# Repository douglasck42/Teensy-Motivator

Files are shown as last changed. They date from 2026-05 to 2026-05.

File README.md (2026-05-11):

# Teensy-Motivator
Teensy 4.1 Based Droid Control. This code coveres the primary Teensy 4.1 system which it's primary job is converting inputs to outputs, trigging programmatic automation of events, triggering MP3s and LED sequences, and even override normal input/output maps for the purposes of automation.

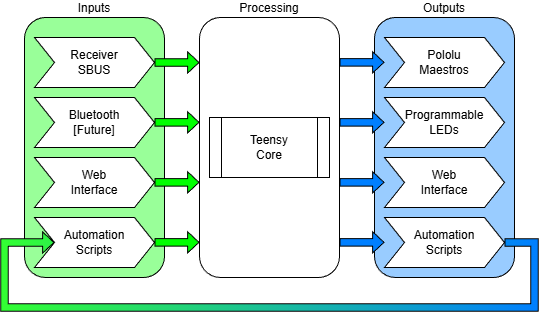
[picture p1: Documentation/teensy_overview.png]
Teensy 4.1 Overview


## System Architecture
* Core System - This `Teensy Motivator` Repository
    * Teensy 4.1
    * DFPlayer Mini
    * Pololu D36V50F5 5v Voltage Regulator (accepting 5.5-50v DC input)
    * An available PCB Board simplifying the mounting of all of this (Hardware v1.0)
* Control System - Optional - `Teensy Scomp Link` Repository
    * Adafruit Sparkle Mini ESP32 Arduino
    * Attached via Serial Port to the Teensy 4.1
    * Provides 2 banks of WS2812b or 5050 LEDs
    * Provides Wireless Control - both a Web Interface and remote triggers via ESP-NOW
* Remote System - Optional - `Teensy Scomp Relay` Repository
    * Adafruit Sparkle Mini ESP32 Arduino
    * Provides 2 banks of WS2812b or 5050 LEDs
    * Listens for ESP-NOW Triggers to run LED animations
* KyberPad
    * From the Kyber team - Provides LUA scripts for up to 3 screens of 15 buttons each
    * Enables the triggering of MP3s, Automation, Etc
    * Seperate Purchase required

## Inputs:
    - Single Input: SBUS-16 or SBUS-24
    - Web Interface `Teensy Scomp Link`
    - KyberPad R/C Triggers
    - Serial Console for debugging and test bench work

## Outputs:
    - LEDs: Triggered via Serial communications Adafruit Sparkle
    - Serial2: DFPlayer music trigger
    - Serial3: Pololu Maestro or Similar (MARCduino, etc)
    - Serial4: Pololu Maestro or Similar (MARCduino, etc)
    - Serial5: Teensy Scomp Link (Adafruit Sparkle Motion)
    - Serial6: Pololu Maestro or Similar (MARCduino, etc)
    - Serial7: Pololu Maestro or Similar (MARCduino, etc)
    - Serial8: SBUS (FrSky Receiver)
    - Can Bus 1: Robotic Actuators, etc
    - Can Bus 3: Robotic Actuators, etc
    - Web Interface via Wi-Fi (status messages, etc)
    - Two GPIO Pins (11,12 and 40, 41) - Future Possibilities
    - I2C - Future Possibilities

## LED Animations
    - (TBD...)

## Maestro Serial Animations
    # 1-Axis Random Idle - Randomly Move a servo
    # 2-Axis Random Idle - Randomly Move a servo
    # 2-Axis Random Spinner - Randomly trigger DC Motor spins (B2EMO Tool Spinners)
    # 2-Axis Fixed Spinner - trigger DC Motor spins on a set sequence (B2EMO Tool Spinners)
    # 3-Axis Random Head Idle - Given 3 axis, randomly move a head unit around (BB-8 or B2EMO Simple Head)
    # 4-Axis Random Head Idle - Given 4 axis, randomly move a head unit around (B2EMO DF-Pro Head)
    
# FrSky SBUS Tuning
The FrSky SBUS does not have great documentation.

## SBUS-16 or SBUS-24
First things first, right now it's a compiled setting. Pick on and that's that.

## SBUS Min/Max
If all of you outputs DO NOT exceed 100% then you can ignore this section. If you want more granular control below that, you may need to tune the min/max

If you outputs are **RESTRICTED below 100%**, you probably STILL want to **IGNORE THIS section**

If this isn't mapped properly, you won't get to min/max ratios proper. Either coming up short or blowing past a software limiter. If you're using Pololu Maestros those values, if changed, must match as well!

For SBUS, at **100%** from the FrSky transmitter, Minimum SBUS is `172` and maximum is `1810` - You change the `sbus_standard_min` and `sbus_standard_max` values if desired for default all-channel behavior.

For SBUS, at **125%** from the FrSky transmitter, Minimum SBUS is `0` and maximum is `2047` but in practice, I've only seen and configured the system for `8` and `1976`. You change the `sbus_abs_min` and `sbus_abs_max` values if desired for default all-channel behavior. 

Going above **125%** isn't supported, is discouraged by the FrSky transmitter GUI on the X20-RS, and I don't know what will happen.

Per-channel default is to use the system-wide standard values if the **per-channel default setting sbus_abs_minmax = false**. Setting **sbus_abs_minmax = true** uses the absolute full range values. Directly configuring channel[x].min and channel[x].max values uses THOSE no matter the boolean value.

## Reciever Output Warning
**On my lab bench, my TD SR6 cannot and will not transmit the absolute values (expanded range). The TD R6 and TD R10 CAN**. Unfortunatly you will have to expirement yourself to know for sure. 

*Both receivers on the v3.0.3 firmware which isn't even available for download for the TD R6*

## Pololu Maestros
As with the SBUS min/max values, if this isn't mapped properly, you won't get to min/max ratios proper. With the Maestro min/max you can't exceed that so you're safe, but if you want the physical min/max to match, these values MUST match.

The default maestro values are `992µs` min and `2000µs` max as defined by settings.maestro_standard_min and settings.maestro_standard_max

The absolute min/max maestro values are `496µs` and `2496µs` as defined by settings.maestro_abs_min and settings.maestro_abs_min.

As with SBUS, the per-channel setting of maestro_100_pct 

## License

Firmware:
This project’s firmware is licensed under the GNU General Public License v3.0 (GPL-3.0).

Third-party components:
This project includes third-party libraries, including SBUS from Bolder Flight Systems, licensed under the GNU Lesser General Public License v3.0 (LGPL-3.0). Any modifications to those libraries are provided in accordance with their licenses.

Use at your own risk. No warranty. Verify designs before manufacturing.

Authors Note:
I'm inspired by the openness of the "droid building" community - the sharing and freely publishing complex designs and the work effort to arrive at those. I don't expect this project to be as "off-the-shelf" as other niche products with closed ecosystems (they are needed), but I wanted something more open, free, and extensible. This is that effort. I started droid building with B2EMO, so I will limit my thanks to the names of individuals who have been attached to that effort: Michael Baddeley, David Ferreria, Tim Hebel for the 3d designs and plans, and Jason Charlton's Youtube build videos.

© 2026 Douglas Kempthorne (douglas@kempthorne.com)

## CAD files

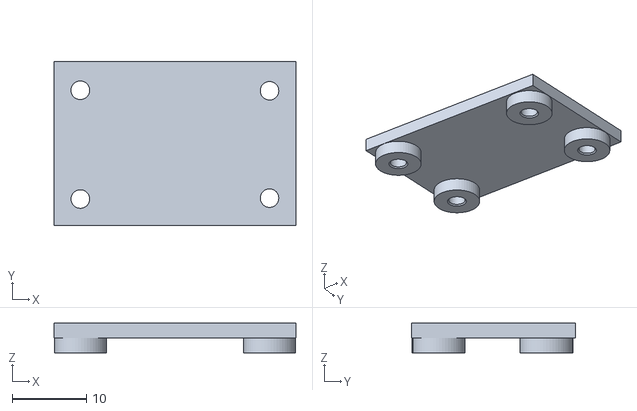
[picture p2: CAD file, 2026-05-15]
Documentation/Sparkle Mini PCB Surface Mount.stl
32.5 x 22.0 x 4.00

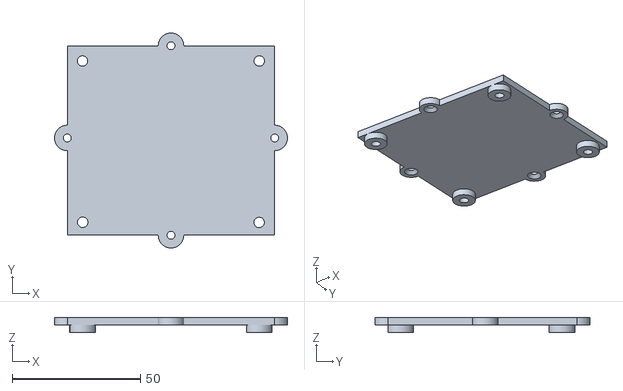
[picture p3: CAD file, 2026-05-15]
Documentation/Teensy Motivator v1.1 Surface Mount with Standoffs.stl
91.0 x 84.0 x 6.00

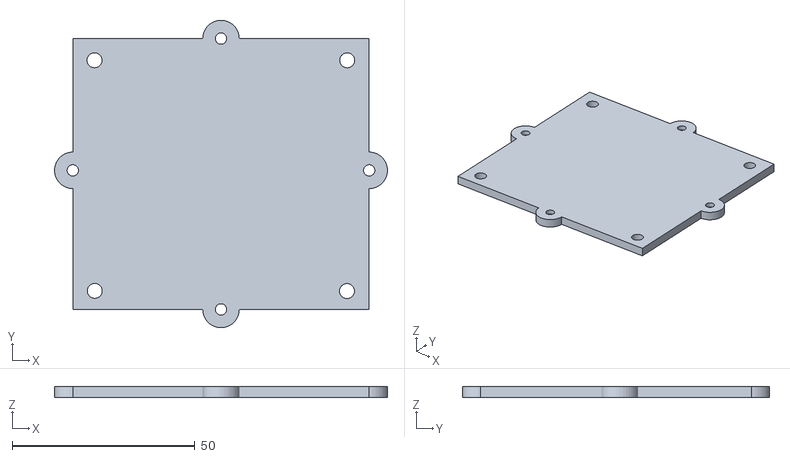
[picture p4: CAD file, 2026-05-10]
Documentation/Teensy Motivator v1.1 Surface Mount.stl
91.0 x 84.0 x 3.00

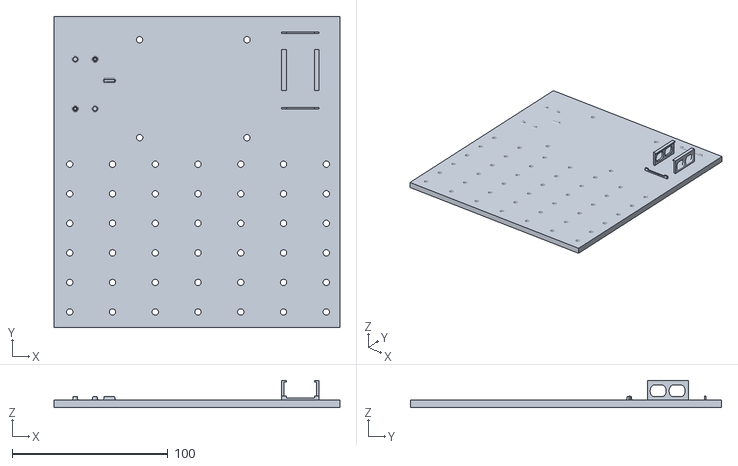
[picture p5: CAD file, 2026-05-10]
Documentation/Teensy Motivator v1.1 Work Surface.stl
183.7 x 200.0 x 17.5

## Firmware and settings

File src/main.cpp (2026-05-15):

// Copyright (c) 2026 Douglas Kempthorne (douglas@kempthorne.com)
// SPDX-License-Identifier: GPL-3.0-or-later

#define BUILD_VERSION "0.2.0"
#include <Arduino.h>
//#include <LittleFS.h>
#include "sbus/sbus_config.h"
#include "settings.h"
#include "dfplayer/dfp.h"
#include "kyberpad/kyberpad.h"
#include "maestro/maestro.h"
#include "json/JsonStorage.h"
#include "scomp/scomp_serial.h"

// Watching flags
#ifndef WATCHDOG_ENABLED
#define WATCHDOG_ENABLED 1
#endif
#ifndef WATCHDOG_TIMEOUT_SECONDS
#define WATCHDOG_TIMEOUT_SECONDS 10
#endif
#if WATCHDOG_ENABLED
#include <esp_task_wdt.h>
#endif

// Other timer values
#ifndef HEARTBEAT_INTERVAL_MS
#define HEARTBEAT_INTERVAL_MS 5000
#endif
#ifndef PRINT_ALL_INTERVAL_MS
#define PRINT_ALL_INTERVAL_MS 30000
#endif

#ifndef WAIT_FOR_SERIAL
#define WAIT_FOR_SERIAL 0
#endif

#ifndef DEBUG_SCOMP_RX
#define DEBUG_SCOMP_RX 0
#endif
#ifndef SCOMP_BAUD_RATE
#define SCOMP_BAUD_RATE 115200
#endif
static unsigned long millis_lastHeartbeat = 0;
static unsigned long g_last_scomp_ms = 0;


// Hand off the serial port here - Serial1 = pins 0/1 on Teensy 4.1
SbusDriverType sbusHandler(&SBUS_SERIAL);
Maestro maestro;
ScompSerial scomp;

// Define all functons:
void inputOutputMapping(uint8_t channel, unsigned long now);
void ioVolume(uint8_t channel);

char* formatUptime(unsigned long ms) {
    static char buf[32];
    unsigned long seconds = ms / 1000;
    unsigned long minutes = seconds / 60;
    unsigned long hours   = minutes / 60;
    unsigned long days    = hours   / 24;

    seconds %= 60;
    minutes %= 60;
    hours   %= 24;

    if (days > 0)
        sprintf(buf, "%lud %02luh %02lum %02lus", days, hours, minutes, seconds);
    else if (hours > 0)
        sprintf(buf, "%02luh %02lum %02lus", hours, minutes, seconds);
    else if (minutes > 0)
        sprintf(buf, "%02lum %02lus", minutes, seconds);
    else
        sprintf(buf, "%02lus", seconds);

    return buf;
}

// ========================= SCOMP =========================
void onScompMessage(uint8_t msg_type, const uint8_t *payload, uint16_t len, void *) {
    g_last_scomp_ms = millis();
    switch (msg_type) {
        case SCOMP_MSG_HEARTBEAT: {
            static unsigned long millis_lastEspHeartbeat = 0;
            unsigned long now_hb = g_last_scomp_ms;
            unsigned long gap = millis_lastEspHeartbeat ? (now_hb - millis_lastEspHeartbeat) : 0;
            millis_lastEspHeartbeat = now_hb;
            if (len >= sizeof(ScompHeartbeat)) {
                const auto *hb = reinterpret_cast<const ScompHeartbeat *>(payload);
                Serial.printf("Heartbeat: Teensy UP %s", formatUptime(now_hb));
                Serial.printf(" | Scomp UP %s", formatUptime(hb->uptime_ms));
                Serial.printf(" | v%u flags=0x%02X gap=%lums\n", hb->version, hb->flags, gap);
            } else {
                Serial.printf("Heartbeat: Teensy UP %s | Scomp FAULT | short payload %u bytes\n", formatUptime(now_hb), len);
            }
            break;
        }
        case SCOMP_MSG_REQUEST_STATE: {
            if (settings.system.debug) Serial.println("SCOMP: ESP32 requested state dump");
            // full state will be sent on the next scompSendState() tick
            break;
        }
        case SCOMP_MSG_SET_VOLUME: {
            if (len < sizeof(ScompSetVolume)) break;
            const auto *msg = reinterpret_cast<const ScompSetVolume *>(payload);
            uint8_t vol = constrain(msg->volume, settings.audio.min, settings.audio.max);
            dfpVolume(vol);
            settings.audio.volume = vol;
            if (settings.system.debug) Serial.printf("SCOMP: Set volume → %u\n", vol);
            break;
        }
        case SCOMP_MSG_TRIGGER_AUDIO: {
            if (len < sizeof(ScompTriggerAudio)) break;
            const auto *msg = reinterpret_cast<const ScompTriggerAudio *>(payload);
            dfpPlay(msg->file_number);
            if (settings.system.debug) Serial.printf("SCOMP: Trigger audio → file %u\n", msg->file_number);
            break;
        }
        case SCOMP_MSG_SET_SETTING: {
            if (len < sizeof(ScompSetSetting)) break;
            const auto *msg = reinterpret_cast<const ScompSetSetting *>(payload);
            if (settings.system.debug) Serial.printf("SCOMP: Set setting key=0x%02X idx=%u val=%u\n",
                                                      msg->key, msg->index, msg->value.u8);
            switch (msg->key) {
                case SCOMP_SETTING_AUDIO_MUTE:
                    settings.audio.mute = (msg->value.u8 != 0);
                    if (settings.audio.mute) dfpVolume(0);
                    else dfpVolume(settings.audio.volume);
                    break;
                default: break;
            }
            break;
        }
        default:
            Serial.printf("SCOMP: Unknown message type 0x%02X len=%u\n", msg_type, len);
            break;
    }
}

void scompSendState(unsigned long now) {
    // Input channels
    ScompInputChannels in_msg = {};
    for (uint8_t i = 0; i < SCOMP_IN_CH; i++) {
        in_msg.values[i] = settings.ichannel[i].sbus_value;
        if (settings.ichannel[i].enabled) in_msg.enabled[i / 8] |= (1u << (i % 8));
    }
    scomp.sendInputChannels(in_msg);

    // Output channels
    ScompOutputChannels out_msg = {};
    for (uint8_t i = 0; i < SCOMP_OUT_CH; i++) {
        out_msg.values[i] = settings.ochannel[i].us_value;
        if (settings.ochannel[i].enabled) out_msg.enabled[i / 8] |= (1u << (i % 8));
    }
    scomp.sendOutputChannels(out_msg);

    // Audio state
    ScompAudioState audio_msg = {};
    audio_msg.volume = settings.audio.volume;
    audio_msg.state  = dfpIsPlaying() ? SCOMP_AUDIO_PLAYING : SCOMP_AUDIO_STOPPED;
    scomp.sendAudioState(audio_msg);
}

#ifndef SCOMP_SEND_INTERVAL_MS
#define SCOMP_SEND_INTERVAL_MS 50   // 20 Hz channel updates to ESP32
#endif


// ========================= CONFIG =========================
// 0 = auto-detect, 16 = SBUS-16, 24 = SBUS-24 - this value is fungible in the hopes of adding in detection for SBUS-16 vs SBUS-24 in the future, but for now it is just used to select the driver and set the expected number of channels
uint8_t SBUS_CHANNELS = 0;
const uint8_t SBUS_INTERVAL_MS = 15; // Slightly over 14ms SBUS frame rate, you probably don't want to change this
constexpr uint8_t SBUS_LATE_WARNING_MS = 5;   // warn if we're this many ms late
constexpr uint16_t SBUS_WARN_COOLDOWN_MS   = 1000; // suppress repeated warnings for this long

void loadSettingsWrapper();

// ========================= SETUP =========================
void setup() {
    Serial.begin(115200);
#if WAIT_FOR_SERIAL == 1
    if (WAIT_FOR_SERIAL) {
        while (!Serial) {
            delay(100);
        }
    }

    Serial.println("Teensy Motivator v" BUILD_VERSION ": starting up... (serial required)");
#else
    delay(2000); // Wait for Serial to be ready but non-blocking
    Serial.println("Teensy Motivator v" BUILD_VERSION ": starting up... (serial optional)");
#endif


    Serial.print("Initializing Serial Ports");
    static uint8_t Serial4_tx_buf[256];
    static uint8_t Serial5_tx_buf[512];  // scomp TX: headroom for config upload chunks
    static uint8_t Serial5_rx_buf[512];  // scomp RX: ~3 SBUS cycles of headroom at 115200
    static uint8_t Serial6_tx_buf[256];
    // 57600, 115200 - it's all static right now so
    // Serial2 - Handled by dfp.h and dfp.cpp
    Serial3.begin(115200);
    Serial4.begin(115200);
    Serial5.begin(SCOMP_BAUD_RATE);  // Scomp Motion (ESP32)
    Serial6.begin(115200);
    Serial7.begin(115200);  // Maestro static for now
    // Serial8 - Handled by SBUS

    Serial4.addMemoryForWrite(Serial4_tx_buf, sizeof(Serial4_tx_buf));
    Serial5.addMemoryForWrite(Serial5_tx_buf, sizeof(Serial5_tx_buf));
    Serial5.addMemoryForRead(Serial5_rx_buf,  sizeof(Serial5_rx_buf));
    Serial6.addMemoryForWrite(Serial6_tx_buf, sizeof(Serial6_tx_buf));

    scomp.begin(Serial5);
    scomp.onMessage(onScompMessage);

    // Enable watchdog (5 second timeout)
    #if WATCHDOG_ENABLED
    esp_task_wdt_init(WATCHDOG_TIMEOUT_SECONDS, true);
    esp_task_wdt_add(NULL); // add current thread
    #endif

    loadSettingsDefaults();
    loadSettingsWrapper();

#if SBUS_DRIVER == SBUS_DRIVER_BOLDERFLIGHT
    Serial.println("Driver: Bolderflight SBUS-16");
    SBUS_CHANNELS = 16;
#elif SBUS_DRIVER == SBUS_DRIVER_NATIVE16
    Serial.println("Driver: Native SBUS-16");
    SBUS_CHANNELS = 16;
#elif SBUS_DRIVER == SBUS_DRIVER_NATIVE24
    Serial.println("Driver: Native SBUS-24");
    SBUS_CHANNELS = 24;
#endif

    sbusHandler.begin();
    Serial.println("SBUS handler ready!");

    dfpSetup(); // Configure DFPlayer settings based on the detected state of the player and the SD card. This is called from setup() after initializing the player to ensure that the player is configured correctly before use.

    // force the volume to the mid level
    dfpVolume(settings.audio.initial);
    Serial.printf("DFPlayer: Volume set to %d of %d\n", settings.audio.initial, settings.audio.max);
    settings.audio.volume = settings.audio.initial; // Update the settings with the new volume level

    Serial.println("Teensy Motivator now motivating! (setup complete)");

} // setup()

void loadSettingsWrapper() {
    // Initialize SD card
    if (!JsonStorage::begin(BUILTIN_SDCARD)) {
        Serial.println("setup_load_wrapper(): Teensy 4.1 SD init failed");
        // cfg remains at compiled defaults — safe to continue
    }

    // Load settings — scoped block so JsonDocument is freed immediately after
    {
        if (settingsLoad("/config.json", settings)) {
            Serial.println("Settings loaded");
        } else {
            Serial.println("No config found, using defaults");
            // Optionally write defaults out on first boot:
            settingsSave("/config.json", settings);
        }
    }

    settingsSave("/config_backup.json", settings); // Backup the loaded (or default) settings for debugging purposes
    
}
Stream& getSerialPort(uint8_t port) {
    switch (port) {
        case 1: return Serial1;
        case 2: return Serial2;
        case 3: return Serial3;
        case 4: return Serial4;
        case 5: return Serial5;
        case 6: return Serial6;
        case 7: return Serial7;
        case 8: return Serial8;
        default: return Serial;  // fallback to USB serial
    }
}

// Print out ALL SBUS Channels (Remember that index 0 is channel 1 in SBUS)
void printAllChannels() {
    Serial.print("SBUS: ");
    for (uint8_t i = 0; i < SBUS_CHANNELS; i++) {
        Serial.printf("Ch%d:%d ", i + 1, sbusHandler.channel(i));
    }
    Serial.println("");
}

uint16_t sbusToMicroseconds(uint8_t channel) {
    return map(settings.ichannel[channel].sbus_value, sbusGetMin(channel), sbusGetMax(channel), usGetMin(CH_IN, channel), usGetMax(CH_IN, channel));
}

// Read the SBUS values and save them to the settings.ichannel[] array
// We don't actually DO anything here except save them (.sbus_value AND .us_value)
void readSbusInputs(unsigned long now) {
    static unsigned long millis_lastSerialOuptut = 0;
    for (uint8_t current_channel = 0; current_channel < SBUS_CHANNELS; current_channel++) {
        int16_t current_value = sbusHandler.channel(current_channel);
        
        current_value = constrain(current_value, sbusGetMin(current_channel), sbusGetMax(current_channel));
        auto& ch = settings.ichannel[current_channel];

        if (ch.sbus_value != current_value) {
            ch.updated = true;      // Downstream functions should ACT on this value
            ch.sbus_value = current_value;
            ch.us_value = sbusToMicroseconds(current_channel);
        }
        if (ch.serial_debug_output && (now - millis_lastSerialOuptut >= settings.system.per_channel_serial_output_throttle)) {
            printChannel(CH_IN, current_channel);
        }
    }
    if (now - millis_lastSerialOuptut >= settings.system.per_channel_serial_output_throttle) {
        millis_lastSerialOuptut = now;
    }
}

//
void inputFunctions(unsigned long now) {
    for (uint8_t current_channel = 0; current_channel < SBUS_CHANNELS; current_channel++) {
        auto& ch = settings.ichannel[current_channel];
        if (ch.updated) {
                 
            switch (ch.channelFunction) {
                case iChannelFunction::KYBERPAD:
                    ch.updated = false;     // We're calling the function, turn this off now
                    ioKyberpadButtons(current_channel, now);
                    break;
                case iChannelFunction::KYBERPAD_PAGE:
                    ch.updated = false;     // We're calling the function, turn this off now
                    ioKyberpadPage(current_channel);
                    break;
                case iChannelFunction::VOLUME:
                    ch.updated = false;     // We're calling the function, turn this off now
                    ioVolume(current_channel);
                    break;
                default: break;
            }
        }
    }
}

// consider the output channels and make things happen
void sendOuputs(unsigned long now) {
    static unsigned long millis_output = now;
    bool do_debug = (now - millis_output >= settings.system.per_channel_serial_output_throttle);
    bool did_debug = false;
    for (uint8_t current_channel = 0; current_channel < NUM_OUTPUT_CHANNELS; current_channel++) {
        auto& och = settings.ochannel[current_channel];
        if (!och.enabled || !och.updated) continue;
        och.updated = false;        // we're processing the channel now, clear this

        // splash of debug output
        if (och.serial_debug_output && do_debug) {
            ioPrintChannel(current_channel, och.ichannel);
            did_debug = true;
        }

        if (och.serial_port_out > 2 && och.serial_port_out < 9 && och.maestro_id > 0) {
            maestro.setTarget(getSerialPort(och.serial_port_out), och.maestro_id, och.maestro_ch, och.us_value);
        }
    }
    if (do_debug && did_debug) millis_output = now;
}

// Handle the processing of Input/Outputs
void outputMapping(unsigned long now) {
    #define outputMappingDebug 0    // Set to 1 to enable the outputMapping debug serial output; developer special

    #if outputMappingDebug == 1
    static unsigned long millis_output = now;
    bool do_debug = (now - millis_output >= settings.system.per_channel_serial_output_throttle);
    bool did_debug = false;
    #endif

    for (uint8_t current_channel = 0; current_channel < NUM_OUTPUT_CHANNELS; current_channel++) {
        auto& och = settings.ochannel[current_channel];

        // Skip processing for this channel if it's not enabled
        if (!och.enabled) continue; 

        if (och.ichannel_enabled) {
            auto& ich = settings.ichannel[och.ichannel];
            if (ich.updated) {
                och.updated = true;
                // adjust the relative µs values to match input channel 100% to output channel 100%
                och.us_value = map(ich.us_value, usGetMin(CH_IN, och.ichannel), usGetMax(CH_IN, och.ichannel), usGetMin(CH_OUT, current_channel), usGetMax(CH_OUT, current_channel));

                ich.updated = false;        // we've processed it, clear it
                #if outputMappingDebug == 1
                if (och.serial_debug_output && do_debug) {
                    ioPrintChannel(current_channel, och.ichannel);
                    did_debug = true;
                }
                #endif
            }
        }
    }

    #if outputMappingDebug == 1
    if (do_debug && did_debug) millis_output = now;
    #endif

}

void ioVolume(uint8_t channel) {
    // Map the SBUS value to a volume level between 0 and 30
    int8_t volume = map(settings.ichannel[channel].us_value, usGetMin(CH_IN, channel), usGetMax(CH_IN, channel), settings.audio.min, settings.audio.max);
    volume = constrain(volume, settings.audio.min, settings.audio.max);
    if (volume != settings.audio.volume) {
        dfpVolume(volume);
        Serial.printf("DFPlayer: Volume set to %d of %d\n", volume, settings.audio.max);
        settings.audio.volume = volume; // Update the settings with the new volume level
    }
}


// ========================= LOOP =========================
void loop() {
    unsigned long now = millis();

    // timers, these get set to current millis() at various points in the code to manage timing of different functions and features
    static unsigned long millis_lastSbusRead    = now;
    static unsigned long millis_lastPrintAll    = now;
    static unsigned long millis_lastSbusWarn    = now; // tracks last time we emitted a late warning
    static unsigned long millis_lastScompSend = now;
    static unsigned long millis_lastScompHeartbeat = now;

    //static unsigned long millis_maestro = 0; //
    //static uint16_t maestro_position = 6000; //

    // watchdog reset to prevent system hangs, especially important if the SD card is missing or there's an issue with the DFPlayer that could cause blocking calls
    #if WATCHDOG_ENABLED
    esp_task_wdt_reset();
    #endif

    // Scomp update to read incoming messages and trigger callbacks - this should be called every loop tick to ensure timely processing of incoming Scomp messages from the ESP32
    scomp.update();

    // Heartbeat (USB serial)
    if (now - millis_lastHeartbeat >= HEARTBEAT_INTERVAL_MS) { // add a little extra time to ensure this doesn't get too close to the Scomp heartbeat, which is on the same timer
        bool scomp_alive = g_last_scomp_ms > 0 && (now - g_last_scomp_ms) < (HEARTBEAT_INTERVAL_MS * 2);
        if (!scomp_alive) {
            #if DEBUG_SCOMP_RX
            Serial.printf("Heartbeat: Teensy UP %s | Scomp DOWN | rx bytes=%lu frames=%lu crc_err=%lu sync_drops=%lu\n",
                          formatUptime(now), scomp.rxBytes(), scomp.rxFrames(), scomp.rxCrcErrors(), scomp.rxSyncDrops());
            #else
            Serial.printf("Heartbeat: Teensy UP %s | Scomp DOWN\n", formatUptime(now));
            #endif
        }
        millis_lastHeartbeat = now;
    }

    // Heartbeat (Scomp)
    if (now - millis_lastScompHeartbeat >= HEARTBEAT_INTERVAL_MS) {
        ScompHeartbeat hb = {};
        hb.version   = SCOMP_PROTOCOL_VERSION;
        hb.uptime_ms = now;
        hb.flags     = (sbusHandler.failsafe()  ? SCOMP_FLAG_SBUS_FAILSAFE   : 0)
                     | (sbusHandler.lostFrame() ? SCOMP_FLAG_SBUS_LOST_FRAME : 0);
        scomp.sendHeartbeat(hb);
        millis_lastScompHeartbeat = now;
    }

    // Periodic state push to ESP32
    if (now - millis_lastScompSend >= SCOMP_SEND_INTERVAL_MS) {
        millis_lastScompSend = now;
        scompSendState(now);
    }
    if (now - millis_lastPrintAll >= PRINT_ALL_INTERVAL_MS) {
        printAllChannels();
        millis_lastPrintAll = now;
    }

    // SBUS Input and output handling
    if ((now - millis_lastSbusRead) >= SBUS_INTERVAL_MS) {

        // Generate warnings if we're running late - indictive of code running to slow or too blocking somewhere else
        unsigned long actualInterval = now - millis_lastSbusRead;
        if (actualInterval > (SBUS_INTERVAL_MS + SBUS_LATE_WARNING_MS)) {
            if ((now - millis_lastSbusWarn) >= SBUS_WARN_COOLDOWN_MS) {
                millis_lastSbusWarn = now;
                Serial.printf("[WARN] SBUS poll late: %lu ms (expected %u ms)\n", actualInterval, SBUS_INTERVAL_MS);
            }
        }

        // Update the timer and read the sbus
        millis_lastSbusRead = now;
        if (sbusHandler.read()) {
            readSbusInputs(now);
            if (sbusHandler.failsafe())  Serial.println("SBUS: ** FAILSAFE **");
            if (sbusHandler.lostFrame()) Serial.println("SBUS: ** LOST FRAME **");
        }

        inputFunctions(now);        // Handling of predefined input functions (like kyberpad)
        outputMapping(now);         // Create maps of user outputs
        // run programmatic automation/scriptings tools
        sendOuputs(now);            // write the serial output queues

    }

}

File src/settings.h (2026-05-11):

// Copyright (c) 2026 Douglas Kempthorne (douglas@kempthorne.com)
// SPDX-License-Identifier: GPL-3.0-or-later

#pragma once
#include <Arduino.h>
#include "json/JsonStorage.h"

#define NUM_INPUT_CHANNELS 24     // SBUS may have 16 or 24, we don't really care here which
#define NUM_OUTPUT_CHANNELS 48    // Maximum number of Output channels, currently a uint8_t so 255 is THE maximum

// Kyberpad Screen Fixes Values
#define PAGES 3           // 3 Pages
#define ROWS 3            // 3 rows
#define COLUMNS 5         // 5 columns
#define BUTTON_COUNT 16   // 15 buttons in total on a screen plus a null value for no buttons pressed

enum class iChannelFunction : uint8_t {
    NONE = 0,
    KYBERPAD,
    KYBERPAD_PAGE,
    VOLUME,
    SERVO_DIRECT,
};
struct iFunctionMap {
    const char* name;
    iChannelFunction function;
};
iChannelFunction iLookupFunction(const String& name);

enum class oChannelFunction : uint8_t {
    NONE = 0,
    SERVO_DIRECT,
};
struct oFunctionMap {
    const char* name;
    oChannelFunction function;
};
oChannelFunction oLookupFunction(const String& name);

enum class ChannelType : uint8_t {
    iCHANNEL,
    oCHANNEL
};
#define CH_IN  ChannelType::iCHANNEL
#define CH_OUT ChannelType::oCHANNEL

#define JITTER 20

struct Settings {

    // ---------- AUDIO ----------
    struct Audio {
        uint8_t volume = 15;
        uint8_t min = 0;
        uint8_t initial = 15;
        uint8_t max = 30;
        bool mute = false;
        uint16_t sbus_min = 172;    // The minimum SBUS value that corresponds to volume 0. This is used for mapping the SBUS input range to the volume range.
        uint16_t sbus_max = 1810;   // The maximum SBUS value that corresponds to the maximum volume. This is used for mapping the SBUS input range to the volume range.
        bool dfp_debug = false; // Flag to indicate whether to print DFPlayer-related debug information to the serial console. This can be useful for verifying that audio controls are working as expected, but can be very verbose, so it is disabled by default.

        void to_json(JsonObject obj) const {
            obj["volume"]    = volume;
            obj["min"]       = min;
            obj["initial"]   = initial;
            obj["max"]       = max;
            obj["mute"]      = mute;
            obj["sbus_min"]  = sbus_min;
            obj["sbus_max"]  = sbus_max;
            obj["dfp_debug"] = dfp_debug;
        }

        void from_json(JsonObjectConst obj) {
            volume    = obj["volume"]    | volume;
            min       = obj["min"]       | min;
            initial   = obj["initial"]   | initial;
            max       = obj["max"]       | max;
            mute      = obj["mute"]      | mute;
            sbus_min  = obj["sbus_min"]  | sbus_min;
            sbus_max  = obj["sbus_max"]  | sbus_max;
            dfp_debug = obj["dfp_debug"] | dfp_debug;
        }

    } audio;

    // ---------- SYSTEM ----------
    struct System {
        bool debug = false;                 // generic debug flag for miscellaneous serial output
        bool debug_sbus = false;            // debug flag for SBUS input values. If true, will print out all SBUS channel values on each read. Can be very verbose, so use with caution.        
        bool debug_io_mapping = false;      // debug flag for input/output mapping. If true, will print out the channel and value of each SBUS input that triggers a mapping function. Useful for verifying that inputs are being read and mapped correctly.
        bool debug_audio = false;           // debug flag for audio-related output. If true, will print out information related to audio control, such as volume changes. Useful for verifying that audio controls are working as expected.
        uint8_t num_ichannels = NUM_INPUT_CHANNELS;
        uint8_t num_ochannels = NUM_OUTPUT_CHANNELS;

        uint16_t sbus_standard_min = 172;    // Defaults for 100 Percent on the SBUS with 100% Min from the FrSky
        uint16_t sbus_standard_max = 1810;   // Defaults for 100 Percent on the SBUS with 100% Max from the FrSky
        uint16_t sbus_abs_min = 8;           // Defaults for 125 Percent on the SBUS with 125% Min from the FrSky - In theory this is really 0-2047 but I've never observed less than 8 or more than 1976
        uint16_t sbus_abs_max = 1976;        // Defaults for 125 Percent on the SBUS with 125% Max from the FrSky - In theory this is really 0-2047 but I've never observed less than 8 or more than 1976
        uint16_t sbus_jitter = JITTER;       // SBUS jitter value thresholds (kyberpad and switches)
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

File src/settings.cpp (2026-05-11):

// Copyright (c) 2026 Douglas Kempthorne (douglas@kempthorne.com)
// SPDX-License-Identifier: GPL-3.0-or-later

#include "settings.h"
#include <LittleFS.h>

#define zIdx(x) ((x) - 1)

Settings settings;

//static const char* FILE_PATH = "/config.json";

// -------------------- DEFAULTS --------------------
void resetSettingsDefaults() {
    settings = Settings(); // resets to struct defaults
}

// Channel Functions Definitions
const iFunctionMap IFUNCTION_MAP[] = {
    {"kyberpad",      iChannelFunction::KYBERPAD},
    {"kyberpad_page", iChannelFunction::KYBERPAD_PAGE},
    {"volume",        iChannelFunction::VOLUME},
    {"servo_direct",  iChannelFunction::SERVO_DIRECT},
};
iChannelFunction iLookupFunction(const String& name) {
    for (const auto& entry : IFUNCTION_MAP) {
        if (name == entry.name) return entry.function;
    }
    return iChannelFunction::NONE;
}

const oFunctionMap OFUNCTION_MAP[] = {
    {"servo_direct",  oChannelFunction::SERVO_DIRECT},
};
oChannelFunction oLookupFunction(const String& name) {
    for (const auto& entry : OFUNCTION_MAP) {
        if (name == entry.name) return entry.function;
    }
    return oChannelFunction::NONE;
}

void printSettings();

// -------------------- LOAD --------------------
void loadSettingsDefaults() {
    Serial.println("Settings: loadSettingsDefaults()");
    settings.system.debug_sbus = false;
    Serial.printf("  Default volume: %d\n", settings.audio.volume);
    Serial.printf("  Debug SBUS: %s\n", settings.system.debug_sbus ? "ON" : "OFF");

    settings.system.debug_io_mapping = true;

    Serial.println("Configuring Input Channels");

    {
        auto& ch = settings.ichannel[zIdx(1)];
        ch.enabled = true;
        ch.description = "Throttle";
        ch.sbus_abs_minmax = false;
        ch.us_min = 496;
        ch.us_max = 2496;
        ch.serial_debug_output = false;
    }

    {
        auto& ch = settings.ichannel[zIdx(2)];
        ch.enabled = true;
        ch.description = "Rudder";
        ch.sbus_abs_minmax = false;
        ch.us_min = 496;
        ch.us_max = 2496;
        ch.serial_debug_output = false;
    }

    {
        auto& ch = settings.ichannel[zIdx(3)];
        ch.enabled = true;
        ch.description = "Left Twist";
    }

    {
        auto& ch = settings.ichannel[zIdx(4)];
        ch.enabled = true;
        ch.description = "Elevator";
    }
    {
        auto& ch = settings.ichannel[zIdx(5)];
        ch.enabled = true;
        ch.description = "Aileron";
    }
    {
        auto& ch = settings.ichannel[zIdx(6)];
        ch.enabled = true;
        ch.description = "Right Twist";
    }
    {
        auto& ch = settings.ichannel[zIdx(7)];
        ch.enabled = true;
        ch.description = "SB 3 Position Switch";
    }
    {
        auto& ch = settings.ichannel[zIdx(8)];
        ch.enabled = true;
        ch.description = "SF 2 Position Switch";
    }

    {
        auto& ch = settings.ichannel[zIdx(9)];
        ch.enabled = false;
        ch.description = "Unused";
    }
    {
        auto& ch = settings.ichannel[zIdx(10)];
        ch.enabled = false;
        ch.description = "Unused";
    }
    {
        auto& ch = settings.ichannel[zIdx(11)];
        ch.enabled = false;
        ch.description = "Unused";
    }
    {
        auto& ch = settings.ichannel[zIdx(12)];
        ch.enabled = false;
        ch.description = "Unused";
    }
    {
        auto& ch = settings.ichannel[zIdx(13)];
        ch.enabled = false;
        ch.description = "Unused";
    }
    {
        auto& ch = settings.ichannel[zIdx(14)];
        ch.enabled = true;
        ch.description = "Slider Left";
    }
    {
        auto& ch = settings.ichannel[zIdx(15)];
        ch.enabled = true;
        ch.description = "Slider Right";
    }

    Serial.println("Configuring Input Channels: KyberPad and volume");
    // Human Channel 22, SBUS Channel 21 (0-indexed in code), is the volume control, which is mapped to a continuous range of volume levels from 0 to 30.
    {
        auto& ch = settings.ichannel[zIdx(22)];
        ch.enabled = true;
        ch.description = "Volume Pot 2 Right Dial";
        ch.channelFunction = iChannelFunction::VOLUME;
    }

    // Human Channel 23, SBUS Channel 22 (0-indexed in code), is the KyberPad page selector, which uses the same SBUS range as volume control but is mapped to discrete page states instead of a continuous volume level.
    {
        auto& ch = settings.ichannel[zIdx(23)];
        ch.enabled = true;
        ch.description = "Kyperpad Page SA";
        ch.channelFunction = iChannelFunction::KYBERPAD_PAGE;
    }

    // Human Channel 24, SBUS Channel 23 (0-indexed in code), is the KyberPad software buttons themselves
    {
        auto& ch = settings.ichannel[zIdx(24)];
        ch.enabled = true;
        ch.description = "Kyperpad Buttons";
        ch.channelFunction = iChannelFunction::KYBERPAD;
    }
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

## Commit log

2026-04-16 Nano WIP
    [Nano Motivator v1.fzz]
2026-04-17 Initial WIP
    [Nano Motivator v1.fzz]
2026-04-17 Ongoing WIP
    [Nano Motivator v1.fzz]
2026-04-22 RIP Nano WIP
    [Teensy Motivator v1.fzz]
2026-05-15 Additional mounts
    [Sparkle Mini PCB Surface Mount.stl, Teensy Motivator v1.1 Surface Mount with Standoffs.stl]
